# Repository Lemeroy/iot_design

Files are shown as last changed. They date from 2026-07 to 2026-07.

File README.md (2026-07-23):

# 卒中卫士 · StrokeGuard

基于 ESP32-S3 多模态感知的脑卒中风险提示智能健康镜。

> 当前权威架构：ESP32-S3 独立完成感知、融合、告警和云端通信；PC 仅作同局域网监控与标定工具。详细设计见 [独立镜端架构规格](docs/superpowers/specs/2026-07-11-standalone-edge-mirror-design.md)。

## 架构

```text
GC2145 + INMP441 + Wi-Fi CSI
              │
              v
┌────────────────────────────────────┐
│ ESP32-S3-WROOM-1 N16R8 独立镜端    │
│ F/S/T/E/B 边缘评分 · 确定性融合     │
│ TFT/语音/LED/蜂鸣器 · 离线告警      │
└──────────────┬─────────────────────┘
               │ MQTT：仅数值评分/建议文本
               v
┌────────────────────────────────────┐
│ EMQX · InfluxDB · FastAPI · 豆包   │
└────────────────────────────────────┘

可选 PC ──同局域网 HTTP──> 状态监控、受限档案配置
```

- 三类物理感知来源：摄像头、麦克风、Wi-Fi CSI。
- 五个评分模态：面部 F、言语 S、舌偏辅助 T、眼动 E、稳定性 B。
- 原始音视频只在镜端处理，绝不上云。局域网原始校准流默认关闭，必须经认证、物理按键授权、可见提示并自动超时。
- 云端大模型只生成建议文本，不能修改或取消镜端确定性告警。
- 产品用于风险提示和就医提醒，不是医疗诊断设备。
- Arm 因镜子视野限制不单独测量；如需补全，应另配可穿戴或外部设备。

## 目录

```text
strokeguard/
├── firmware_esp32/  # ESP-IDF 5.5.3 固件；当前含 CSI、USB、融合和外设脚手架
├── host_pc/         # PyQt5 管理端及 PC 算法对照原型，不是运行依赖
├── cloud/           # EMQX、InfluxDB、FastAPI、大模型和微信小程序
├── docs/            # 架构规格、接线和实施计划
└── scripts/         # 本地与云端部署/联调脚本
```

## 核心契约

### S3 到云端

```text
Topic: strokeguard/<device_id>/uplink
```

```json
{
  "schema_version": 1,
  "seq": 0,
  "scores": {"face": 0, "speech": 0, "tongue": 0, "eye": 0, "csi": 0, "final": 0},
  "level": "normal|warning|danger|insufficient",
  "profile": {"age": 0, "conditions": []},
  "reasons": [],
  "veto_by": [],
  "device_id": "sg-0001",
  "ts": 0
}
```

禁止字段：原始 JPEG、音频、MFCC、关键点和其他可还原生物特征的数据。

### 云端到 S3

```text
Topic: strokeguard/<device_id>/downlink
```

```json
{"schema_version":1,"level":"warning","advice_text":"给本人或家属的安全建议文本","ts":0,"source":"doubao"}
```

### PC 监控

```text
GET  /api/v1/config
PUT  /api/v1/config
```

当前接口只允许读取完整配置和更新 `profile`，采用 Bearer Token、固定请求上限和 revision 乐观锁。Token 存在镜端 NVS 与 PC 系统凭据库，不进入 YAML。设备 ID、网络、MQTT、融合权重、危险阈值和否决规则均不可通过该接口修改。详见 [PC 配置手册](docs/pc-yaml-config.md)。

校准、模型更新和 OTA 仍是规划项；后续实现必须经过认证、镜端物理确认、签名校验和失败回滚。USB-CDC 只用于烧录、恢复和调试遥测，不承担正常运行时的评分输入。

## 融合规则

```text
final = 0.35 * F + 0.25 * S + 0.20 * T + 0.12 * E + 0.08 * B
```

- `face <= 30` 或口角偏移绝对值 `>= 20°`：`danger`。
- `speech <= 35` 且 `p_clear < 0.4`：`danger`。
- 无否决时：`final >= 70` 为 `normal`，`40 <= final < 70` 为 `warning`，`final < 40` 为 `danger`。
- T 只作辅助，不设置单项否决。可用权重不足时返回 `insufficient`，不得把缺失数据当正常。

阈值是项目实现基线，尚不是经临床验证的诊断阈值；精度、时延和 CSI 标定结果均待真机与合规数据实测。

## 当前状态

| 能力 | 状态 |
| --- | --- |
| CSI 端侧评分、USB 帧协议、S3 融合 C 实现 | 已有原型 |
| PC 五模态算法原型与 PyQt5 UI | 已有；当前作为可选监控与 YAML 管理工具 |
| EMQX、InfluxDB、FastAPI、豆包建议链路 | 已部署并完成链路验证 |
| S3 直连 MQTT 与独立离线闭环 | E1 固件已上板；离线融合、CSI、数值上行、InfluxDB 落库及大模型建议下行已完成真机验证 |
| GC2145/INMP441 边缘模型及训练权重 | 未完成；外设和数据到位后实测 |
| 局域网档案管理 API | GET/PUT、鉴权、revision 冲突与 PC Keyring 已完成 |
| 校准、签名更新与 OTA | 未完成；E5/E6 交付 |

## 开发入口

固件环境：ESP32-S3-WROOM-1 N16R8、ESP-IDF v5.5.3、当前串口 `COM3`。
         ESP32-S3-Camera、ESP-IDF v5.5.3、当前串口 `COM4`
```powershell
cd firmware_esp32
idf.py set-target esp32s3
idf.py menuconfig
idf.py build
idf.py -p COM3 flash monitor
```

### 给另一块 ESP32-S3 烧录固件

以下流程只适用于与当前开发板一致的 **ESP32-S3-WROOM-1 N16R8（16 MB Flash、8 MB OPI PSRAM）**。其他 S3 模组的 Flash/PSRAM 配置可能不同，不要直接照搬镜像。

1. 打开 `C:\Users\Administrator\Desktop\IDF_v5.5.3_Powershell.lnk`，进入固件目录并确认新板串口：

   ```powershell
   cd F:\iot_design\firmware_esp32
   Get-CimInstance Win32_SerialPort | Select-Object DeviceID,Name
   idf.py --version
   ```

2. 为新设备配置独立参数：

   ```powershell
   idf.py set-target esp32s3
   idf.py menuconfig
   ```

   在 `StrokeGuard M1a/M1b Config` 中设置 2.4 GHz Wi-Fi、MQTT 地址/账号及唯一 `Device ID`（例如 `sg-0002`）。多块镜子不能共用同一个 `Device ID`，否则网页监控和 MQTT 主题会互相覆盖。不要把生成的 `sdkconfig` 或任何密码提交到 Git。

3. 将下面的 `COM5` 替换为新板实际串口，清除旧 NVS 后构建、烧录并观察启动日志：

   ```powershell
   idf.py -p COM5 erase-flash
   idf.py build
   idf.py -p COM5 flash monitor
   ```

   `erase-flash` 会清除该板原有固件和 NVS，仅对确认可覆盖的目标板执行。退出串口监视按 `Ctrl+]`。

4. 验收：日志应出现 Wi-Fi `GOT_IP`、CSI 启动和 MQTT 连接/上行；随后通过外网演示页连接该板的 `Device ID`，确认 CSI、最终状态和大模型建议能够同步。

若多块板使用**完全相同**的配置，可先执行一次 `idf.py build`，之后逐块更换串口并运行 `idf.py -p COMx flash`，无需重复编译。但正式多设备部署仍应逐块设置唯一 `Device ID` 后重新构建、烧录。详细故障处理见 [固件 README](firmware_esp32/README.md)。

PC 测试：

```powershell
cd host_pc
.venv\Scripts\python.exe -m pytest -q
```

外设引脚尚未由实物接线确认，固件 Kconfig 默认使用 `-1` 表示未分配；不要按猜测启用驱动。接线状态见 [wiring.md](docs/wiring.md)。

## 初赛桌面演示程序

`dist/StrokeGuard-Demo.exe` 默认连接 VPS 上的真实设备 `sg-0001`，只显示实时 F/S/T/E/CSI、镜端融合状态和最新豆包建议。它不提供模拟数据；云端不可达、登录失效、设备离线和模态未接入会分别显示。数据不足时融合评分显示“未形成”，不会把无效的 `0` 误显示为危险评分。

“设备维护”页提供：

- 部署 YAML 编辑与严格校验；
- `device_id`、2.4 GHz Wi-Fi、MQTT 和管理 Token 的运行时输入；
- GC2145 与 NMO432 配置校验，未填写完整 GPIO 时禁止启用；
- COM 口扫描、ESP-IDF v5.5.3 编译、确认后擦除、烧录和串口日志；
- 敏感字段日志脱敏。

启动 EXE 后输入 VPS 演示账号和密码，程序自动连接 `sg-0001`。账号和密码只保留在当前进程会话中。设备部署密钥应通过界面运行时输入或本机环境变量提供，不得写入 Git。

## Preliminary External Monitor

### Camera score link

The camera board and N16R8 use independent USB power and share GND. Connect
camera `GPIO47/SDA` to N16R8 `GPIO8/SDA` and camera `GPIO48/SCL` to N16R8
`GPIO9/SCL`. The camera is the I2C target at address `0x52`; only numeric
F/E/T/stage values cross this link. Raw images remain local.

The authenticated preliminary monitor connects by device ID only after a valid
MQTT uplink in the last 30 seconds. It synchronizes numeric scores, screening
stage, status, and latest LLM advice. Its only device command is bounded
`start`/`cancel` for a guided F/E/T session; it cannot change Wi-Fi, MQTT,
fusion weights, thresholds, veto rules, firmware, or profile. State uses
WebSocket updates with automatic five-second polling fallback.

Invalid image regions remain unavailable. E is an ocular-movement risk prompt
and does not test visual fields; T is auxiliary and never a single-item veto.

HTTPS is the normal mode. Plain HTTP is allowed only for the preliminary demo with `SG_ALLOW_INSECURE_HTTP=1`. Raw audio, raw video, MFCC, landmarks, and ROI remain local and do not appear in demo API or deployment examples.

## Local Camera USB Preview

For GC2145 bring-up only, close other COM4 monitors and run:

```powershell
host_pc\.venv\Scripts\python.exe host_pc\tools\camera_usb_preview.py --port COM4
```

The link uses `921600 8N1`. Frames are requested one at a time, displayed only
in memory, and are not saved or uploaded. The VPS and large-model service never
receive preview images. N16R8 I2C polling remains active during preview.

## 桌面演示机 3D 模型

可打印 OpenSCAD/STL、装配图、爆炸图与打印验收说明位于
[`mechanical/desktop_enclosure`](mechanical/desktop_enclosure/README.md)。紧凑镜身为
`110 x 165 x 40 mm`，使用单件 `front_panel.stl` 和 `12 mm` 圆形摄像头孔；生产目录
仅保留五个当前打印件：壳体、前面板、一体式可拆电子托盘、后盖和桌面底座。摄像头、
N16R8 与 NMO432 先用扎带安装到托盘，再从壳体后方整体插入；开发板孔距和装配间隙
保持参数化，不使用猜测尺寸。

## 医学免责声明

本设备是家庭健康风险提示工具，不是医疗诊断设备，不能替代医生的临床评估与治疗建议。若出现突发面部歪斜、言语不清、单侧肢体无力、视物异常、平衡障碍或意识改变等症状，无论设备结果如何，都应立即拨打 120，不等待复测或云端建议。

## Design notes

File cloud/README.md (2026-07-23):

# 卒中卫士 · 云端 (M5)

优云 VPS 自建 EMQX + InfluxDB + FastAPI + 火山豆包 doubao-1.5-lite。

## 目录

```
cloud/
├── docker-compose.yml
├── .env.example              # 复制为 .env 并填写
├── native/                   # 无 Docker/systemd 的原生部署
│   ├── install.sh            # 下载并校验固定版本运行时
│   ├── start.sh / stop.sh    # 服务生命周期
│   ├── status.sh             # 进程与端口状态
│   └── healthcheck.sh        # 自动化健康检查
├── scripts/
│   ├── gen_certs.sh          # 生成 EMQX 自签 TLS (无域名场景)
│   └── init_mqtt_users.sh    # 创建 MQTT 业务账号
├── emqx/
│   └── certs/                # 证书目录 (脚本填充)
├── backend/
│   ├── Dockerfile
│   ├── requirements.txt
│   └── app/
│       ├── main.py           # FastAPI 入口
│       ├── mqtt_bridge.py    # 订阅 uplink -> Influx + LLM -> 发布 downlink
│       ├── llm_advice.py     # 豆包 doubao-1.5-lite (Volcengine Ark OpenAI 兼容)
│       ├── db_influx.py      # InfluxDB 2.7 writer
│       └── schemas.py        # pydantic 契约
└── miniapp/                  # 微信小程序 (本地预览)
    ├── app.json / app.js / app.wxss
    └── pages/index/
```

## 当前云容器：原生部署（推荐）

当前实例的 PID 1 是 `tini`，并缺少 Docker-in-Docker 所需的
`CAP_SYS_ADMIN`/`CAP_NET_ADMIN`。请使用项目内原生运行时：

```bash
cd /opt/strokeguard/cloud
bash native/install.sh
bash native/start.sh
bash native/status.sh
bash native/healthcheck.sh
```

运行内容全部位于 `cloud/native/`：

- `runtime/`：EMQX 5.7.2、InfluxDB 2.7.11、Python venv
- `state/`：数据库和 EMQX 持久数据
- `logs/`：服务日志
- `run/`：PID 文件
- `downloads/`：经过 SHA256 校验的官方安装包

停止与重启：

```bash
bash native/stop.sh
bash native/start.sh
```

云容器整体重启后需要再次运行 `bash /opt/strokeguard/cloud/native/start.sh`。
若控制台支持“启动命令”，可直接填写该命令。脚本不会修改平台挂载的
`/entrypoint.sh`。

本地 Windows 一键上传并部署：

```powershell
powershell -ExecutionPolicy Bypass -File F:\iot_design\scripts\deploy_cloud_native_interactive.ps1
```

该窗口会分别在上传和远端部署时请求一次 SSH 密码，密码不会写入文件。

若云平台尚未开放公网业务端口，可先在本机建立 SSH 隧道：

```powershell
powershell -ExecutionPolicy Bypass -File F:\iot_design\scripts\open_cloud_tunnel.ps1
```

保持隧道窗口开启，并让上位机使用：

```powershell
$env:SG_MQTT_HOST="127.0.0.1"
$env:SG_MQTT_PORT="11883"
```

本机 FastAPI 为 `http://127.0.0.1:18000`，EMQX Dashboard 为
`http://127.0.0.1:18084`。这些端口只绑定本机回环地址。

## 标准 VPS：Docker Compose 部署

## 部署到 VPS (Ubuntu 22.04, Docker 已装)

### 1. 上传 cloud/ 到服务器

在**本地** PowerShell:

```powershell
# 用 scp 上传 (端口 22)
scp -P 22 -r F:\iot_design\cloud ubuntu@<VPS_HOST>:/tmp/strokeguard-cloud
ssh ubuntu@<VPS_HOST>
sudo mkdir -p /opt/strokeguard
sudo mv /tmp/strokeguard-cloud /opt/strokeguard/cloud
sudo chown -R ubuntu:ubuntu /opt/strokeguard/cloud
```

### 2. 配置 .env

在**服务器**上:

```bash
cd /opt/strokeguard/cloud
cp .env.example .env
vim .env    # 填写下列 5 项:
```

必填:
- `EMQX_DASHBOARD_PASS` — EMQX 18083 管理面板密码
- `MQTT_APP_PASS` — backend 用的 MQTT 密码 (随机字符串)
- `MQTT_HOST_PASS` — host_pc 上位机用的 MQTT 密码 (随机)
- `INFLUX_TOKEN` — 长随机串, 用 `openssl rand -hex 32` 生成
- `VOLC_ARK_API_KEY` — 火山方舟 API Key

### 3. 生成 TLS 证书 (无域名, 用 IP)

```bash
cd /opt/strokeguard/cloud
bash scripts/gen_certs.sh <VPS_HOST>
```

生成 `emqx/certs/ca.crt server.crt server.key`. 客户端将来需要 `ca.crt`.

### 4. 启动

```bash
docker compose up -d
docker compose ps           # 三个容器都是 running
docker compose logs -f backend
```

### 5. 创建 MQTT 账号

```bash
bash scripts/init_mqtt_users.sh
```

### 6. 联调验证

```bash
# 后端健康
curl http://127.0.0.1:8000/health
# {"status":"ok","mqtt":true,"influx":true,"llm":true}

# 手动触发一次 LLM 建议 (不经过 MQTT)
curl -X POST http://127.0.0.1:8000/advice \
  -H "Content-Type: application/json" \
  -d '{
    "scores": {"face":25,"speech":40,"tongue":100,"eye":90,"csi":80,"final":45},
    "level": "danger",
    "profile": {"age":68,"gender":"M","conditions":["hypertension"],"meds":["aspirin"],"stroke_history":false},
    "reasons": ["mouth_angle 22.5deg"]
  }'
```

## host_pc 上位机连云

设置环境变量后启动主界面:

```powershell
$env:SG_MQTT_HOST="<VPS_HOST>"
$env:SG_MQTT_PORT="1883"          # 联调期先用明文; 生产改 8883 + SG_MQTT_TLS=1
$env:SG_MQTT_USER="<MQTT_DEVICE_USER>"
$env:SG_MQTT_PASS="<你在 .env 里填的 MQTT_HOST_PASS>"
$env:SG_DEVICE_ID="sg-0001"

python -m stroke_host.ui.main_window --source real --perception
# 勾选 UI 顶部 Cloud 复选框, 然后 Start
```

启动后:
- host_pc 每 10s (或 level 变化时) uplink 数值评分
- 后端订阅 uplink -> 写 Influx -> 调豆包 -> 发布 downlink
- host_pc 收到 downlink -> UI 建议卡片显示

## 数据契约

见 `backend/app/schemas.py`. 三条主管线:

| 方向 | Topic | 载荷 |
|---|---|---|
| host->cloud | `strokeguard/<dev>/uplink` | `UplinkPayload` |
| cloud->device | `strokeguard/<dev>/downlink` | `DownlinkPayload` |
| miniapp<-cloud | HTTP `/devices/<dev>/latest` | `LatestResp` |

**隐私铁律**: 云端接收的载荷**只有数值分与 profile**, 不含 jpeg/mfcc/坐标. `mqtt_pub.py` 已做严格过滤.

## Preliminary External Monitor

The preliminary external page is a read-only monitor. After login, it connects by device ID only when that device has produced a valid MQTT uplink in the last 30 seconds. It synchronizes only monitoring scores/status and the latest LLM advice.

The score panel is session-based: starting a screening clears the displayed
scores to pending, stages 1-4 collect values without repainting the panel,
stage 5 shows the highest observed F/E values from those preceding stages, and
the completed panel is held for 30 seconds. This is display stabilization only;
device-side fusion, vetoes, alerts, and uploaded numeric scores are unchanged.

It does not synchronize profile, Wi-Fi, MQTT settings, fusion settings, thresholds, veto rules, or remote commands. Raw audio, raw video, MFCC, landmarks, and ROI stay local and are excluded from demo API and deployment examples.

HTTPS is the normal mode. Plain HTTP is allowed only for the preliminary demo when `SG_ALLOW_INSECURE_HTTP=1`; otherwise session cookies remain secure. Set `SG_DEMO_USER`, `SG_DEMO_PASSWORD`, and `SG_DEMO_SESSION_SECRET` together to enable demo login. Leaving any of them incomplete keeps authentication disabled so the normal cloud chain still starts.

## 微信小程序本地预览

无 AppID (touristappid) 只能在**微信开发者工具**里预览:

1. 装 [微信开发者工具](https://developers.weixin.qq.com/miniprogram/dev/devtools/download.html)
2. 打开 `cloud/miniapp/` 目录, 选 "无 AppID 测试"
3. `app.js` 里的 `apiBase` 改成你的 VPS IP
4. 顶部工具 -> 详情 -> 本地设置 -> 勾选 "不校验合法域名..."
5. 编译预览

真机预览需要注册 AppID + HTTPS + 域名 ICP 备案, 属于毕设外围, M5 不做.

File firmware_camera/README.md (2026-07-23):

# StrokeGuard Camera Coprocessor

This ESP-IDF v5.5.3 project targets the Hiwonder ESP32-S3-Cam board
(`ESP32-S3-WROOM-1U-N8R8`) with the onboard GC2145 camera. It runs local
`esp32-camera` YUV422 capture, local PSRAM RGB888 conversion, and ESP-WHO
`human_face_detect`. It computes a quality-gated FAST Face (F) engineering
score from ESP-WHO's five landmarks and a volatile personal neutral baseline.
During an explicitly started guided session it also computes local pupil-motion
E and auxiliary tongue-deviation T scores, then exposes only numeric results to
the N16R8 main controller over I2C.

Raw images are not uploaded. The normal device output is face presence and
normalized geometry only. An explicit USB debug session may send requested
JPEG frames directly to the attached PC; frames are not saved or uploaded.
The USB face box remains a detection diagnostic. The five-point F score is a
risk feature, not a diagnosis, and is not equivalent to evaluated 68-point
facial analysis.

## Wiring

Both boards are powered by their own USB cables. Keep the 5 V jumper between
boards disconnected. Share ground.

| Camera board signal | Camera GPIO | N16R8 GPIO |
| --- | ---: | ---: |
| SDA | 47 | 8 |
| SCL | 48 | 9 |
| GND | GND | GND |

The camera's internal GC2145 DVP/SCCB pins are configured in
`main/camera_capture_adapter.cpp` from the vendor example:

```text
XCLK=15, SCCB_SDA=4, SCCB_SCL=5
D0..D7 = 11,9,8,10,12,18,17,16
VSYNC=6, HREF=7, PCLK=13
```

GC2145 does not provide native JPEG output through `esp32-camera`. The
firmware captures QVGA YUV422 and converts it locally to a reusable RGB888
PSRAM buffer for ESP-WHO. An explicit USB preview request encodes the original
YUV422 frame to JPEG locally; it does not change the normal I2C-only output.
The `esp32-camera` converter emits BGR byte order for YUV422 input, so the
adapter swaps the red and blue channels before ESP-WHO preprocessing. Removing
that normalization prevents reliable face detection on the real board.
The camera uses one frame buffer with `CAMERA_GRAB_WHEN_EMPTY`; real-board
testing showed that the two-buffer latest-frame mode spliced DMA regions from
different frames. The resulting frame rate and inference latency are pending
final measurement.

## I2C Protocol

The camera board is the I2C target on GPIO47/GPIO48:

```text
address:  0x52
register 0x01: 4 bytes: center_x, center_y, width, height
register 0x02: 4 bytes: status, F_score, signed_mouth_angle, quality
register 0x03: 4 bytes: status, E_score, binocular_difference, quality
register 0x04: 4 bytes: status, T_score, signed_offset_percent, quality
register 0x10: write 2 bytes: register, start(1)/cancel(0)
register 0x11: 4 bytes: stage, progress, 0, 0
```

Register `0x01` values are normalized to `0..255`; all zeros mean no face.
For register `0x02`, status `1` means the remaining values are valid and
status `0` means F is unavailable. Score and quality are `0..100`; angle is a
signed degree value in `-90..90`. N16R8 uses register `0x02` for fusion.

Stages are `idle`, `face`, `eye-center`, `eye-left`, `eye-right`, `tongue`,
`done`, and `error`. E and T remain unavailable outside a guided session or
when image quality gates fail. E does not claim visual-field testing. T is an
auxiliary observation only and never acts as a single-item danger veto.
If the tongue stage times out without three valid samples, the session enters
`error` and T remains unavailable; no zero or synthetic tongue score is sent
to fusion.
The tongue color candidate must also extend below the detected mouth line;
lip-colored regions without protrusion remain unavailable.
During a new guided run, the previous valid E/T values remain visible until
replacement results are ready. A tongue-stage failure clears T immediately.
Guided eye steps that do not move in opposite directions are treated as an
unavailable acquisition, not E=0; continuous eye monitoring remains available.

The F feature requires a face at least 64 pixels wide, sufficient eye spacing,
a near-frontal nose position, and eye-line roll within 25 degrees. It removes
eye-line roll from the mouth angle, combines mouth angle with nose-to-mouth
distance asymmetry, and publishes a three-frame median relative to a five-sample
neutral baseline. These are
initial engineering thresholds pending measured sensitivity, specificity,
and K-fold evaluation.

## Build And Flash

Open `C:\Users\Administrator\Desktop\IDF_v5.5.3_Powershell.lnk`:

```powershell
cd F:\iot_design\firmware_camera
idf.py set-target esp32s3
idf.py build
idf.py -p COM4 flash monitor
```

The app uses a custom `3 MB` factory partition and `8 MB` flash because the
embedded ESP-WHO model is larger than the default 1 MB app partition.

## Local USB Preview

Close every COM4 serial monitor before opening the preview; COM4 must be closed
by other programs because one process owns the port. From the repository root:

```powershell
host_pc\.venv\Scripts\python.exe host_pc\tools\camera_usb_preview.py --port COM4
```

The debug protocol uses `921600 8N1`. The PC requests one JPEG at a time, so
preview work stops when the window disconnects. Images remain on the directly
connected PC, are not saved, and are not uploaded to MQTT, VPS, or the large
model. I2C numeric F polling at `0x52`/`0x02` continues during preview.

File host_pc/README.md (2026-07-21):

# StrokeGuard PC 端 M1a

## 初赛演示入口（推荐）

```powershell
cd F:\iot_design\host_pc
.venv\Scripts\python.exe -m stroke_host.demo.window
```

该入口是 `StrokeGuard-Demo.exe` 的源码运行方式：默认登录 VPS 并连接真实设备 `sg-0001`，不读取模拟源、不运行 PC 感知管线，也不生成替代评分。设备维护页可编辑 `config/device-deployment.example.yaml`，填写本次运行使用的 Wi-Fi/MQTT/管理凭据，调用本机 ESP-IDF v5.5.3 完成编译、确认擦除、烧录和串口监视。

麦克风型号为 **NMO432**：3.3V 供电，I2S 引脚为 `SCK/BCLK`、`WS/LRCLK`、`SD/DIN`，并通过 `L/R` 选择声道。GC2145 与 NMO432 的 GPIO 未完整确认时保持 `enabled: false`，程序不会猜测引脚。

下文的模拟源、PC 感知和旧观察窗口仅供研发测试，不属于初赛 EXE 的演示入口。

上位机数据管线：ESP32 帧接入 + AES-GCM 加密落盘 + 24h 自动清理 + 用户档案。

## 目录

```
host_pc/
├── pyproject.toml
├── requirements.txt
├── config/
│   └── profile.yaml            # 用户档案 (age/conditions/meds/...)
├── stroke_host/
│   ├── main.py                 # 入口 CLI
│   ├── io/
│   │   ├── cdc_reader.py       # ESP32 USB-CDC 帧解析
│   │   ├── sim_source.py       # 无硬件桩 (M1a 默认)
│   │   ├── frame_recorder.py   # AES-GCM 落盘 + 定时清理
│   │   └── crc16.py            # 与固件对齐
│   ├── config/profile_loader.py
│   └── utils/crypto.py         # keyring master key + AESGCM
└── tests/                      # pytest (含 CRC 对拍 / 帧解析 / 加密 / 24h 清理)
```

## 安装 (Windows PowerShell)

```powershell
cd F:\物联网设计\host_pc
python -m venv .venv
.\.venv\Scripts\Activate.ps1
python -m pip install -U pip
pip install -e ".[dev]"
```

## 跑桩数据源 (无 ESP32, M1a 默认)

```powershell
python -m stroke_host.main --source sim
# 每秒一帧 heartbeat, csi_score 60~95 随机游走
# Ctrl+C 停止, 落盘至 data\session_<时间>\frames.jsonl.enc
```

## 跑真机 (烧录线到手后)

```powershell
# 先确认哪个 COM 是数据口 (CDC0, Interface 0)
Get-CimInstance Win32_SerialPort | Select-Object Name,DeviceID,Description

python -m stroke_host.main --source cdc --port COM3
```

统计输出示例：

```
cdc stats: ok=612 crc_err=0 resync=1
```

## 实时观察窗口 (M1a Observer, tkinter)

零新增依赖，用于目视监控 csi_score 趋势。

```powershell
python -m stroke_host.gui.observer --source sim
# 或真机
python -m stroke_host.gui.observer --source cdc --port COM3
```

窗口包含：
- 交通灯：red (<30) / yellow (<60) / green (>=60)
- 大号 csi 数字 + 最近 60 帧 sparkline
- 统计：frames / fps / cdc ok/crc_err/resync / 当前 session 目录名
- 日志尾 30 行
- 顶部工具条：切 sim/cdc、改 port、勾选 Record、Start/Stop

## M2 感知算法 (F 面部对称 + S 语音清晰度)

新增依赖：`mediapipe` (可选，未装则 F 分不可用)

```powershell
pip install mediapipe
```

真源模式跑 PC 摄像头+麦克风，同时出 F/S 分：

```powershell
python -m stroke_host.main --source real --perception --no-record
```

输出示例：

```
[#12] data csi=None ts=2  F=94 (mouth_angle 1.7deg)  S=63
[#13] data csi=None ts=2  F=97
```

模块概览：

| 模块 | 功能 | 备注 |
|---|---|---|
| `perception/face_detect.py` | mediapipe FaceMesh 468/478 点封装 (refine_landmarks=True 含虹膜) | 单人 |
| `perception/face_symmetry.py` | 口角连线 θ → F 分 (0-100) | 用双眼外眦补偿头部面内旋转 |
| `perception/landmark68.py` | 468 → iBUG 68 点索引映射 | 供 dlib 兼容脚本复用 |
| `perception/mfcc.py` | 纯 numpy MFCC | 与嵌入式 C 版可 bitmatch |
| `perception/mic_source.py` | sounddevice 系统默认输入 | 16 kHz mono |
| `perception/speech_cnn.py` | S 分, CNN 未训 → 启发式 fallback | `p_clear` 综合 voiced_ratio/HNR/MFCC 稳态 |
| **`perception/tongue_deviation.py`** | Tongue 分 (辅助, 权重 0.08) | 下唇内侧近似, **低置信度不否决** |
| **`perception/eye_gaze.py`** | E 分 (权重 0.12) | mediapipe 虹膜, gaze 共轭比 + 眼裂对称性 |
| **`perception/csi_score.py`** | B 分 (权重 0.08) | 端侧已算, PC 侧透传 |

### Dr.Chen 阈值 (v0, 待临床验证)

| 模态 | 计算 | Danger 线 | Warning 线 |
|---|---|---|---|
| F 面部 | `100 - 4·θ` | θ ≥ 20° | θ > 10° |
| S 言语 | `100·p_clear` | score<35 且 p<0.4 | score<55 |
| T 舌偏 | 分段 (辅助) | r≥0.15 → 30 | r≥0.10 → 50-70 |
| E 眼动 | `100 - 200·|Δgaze|` | dg≥0.30 或 lid_asym | dg≥0.15 |
| B 平衡 (CSI) | 端侧直接输出 | <30 | <60 |

**局限（明示）**：
- F: mediapipe 二维投影对大侧脸敏感
- S: 无临床构音数据集，走启发式，需 SNR>15dB
- T: 无舌头分割模型，本版为下唇偏移近似，**灵敏度低，仅参考**
- E: 需正视镜头 ±20°；戴墨镜/极暗光 iris 失败 → unavailable
- B: 无外发射器，反映"存在感/剧烈动作"而非精确平衡

## 观察窗口升级 (M2+M3, 5 模态卡片)

```powershell
python -m stroke_host.gui.observer --source real --perception
```

窗口现包含：
- 总指示交通灯 + 大号"最低模态分"数字（宁误报保守策略）
- **5 张模态卡片**：F / S / T / E / B，各自变色 + 数字
- 60 帧 sparkline
- Perception 复选框（勾选后 data 帧走完整感知流水线）

## M4 主界面 (PyQt5 · 正式版)

新增依赖：

```powershell
pip install -e ".[ui]"     # 安装 PyQt5 + pyttsx3
```

启动：

```powershell
python -m stroke_host.ui.main_window --source real --perception
```

功能：

- **五模态融合**：`final = 0.35·F + 0.35·S + 0.08·T + 0.14·E + 0.08·B`
- **单项否决**（Ark + Dr.Chen 会签，宁误报）：
  - F ≤ 30 或 mouth_angle ≥ 20° → **danger**（红灯闪烁 + 语音"检测到面部不对称,请立即就医并拨打 120"）
  - S ≤ 35 且 p_clear < 0.4 → **danger**（"检测到言语不清..."）
  - E < 30 或 B < 30 → 从 normal 提升为 **warning**
- **不可用模态自适应**：某模态 score=-1 时权重按比例重分；可用总权重 <0.5 → level="insufficient"
- **UI 组成**：
  - 左：180×180 交通灯（danger 时 400ms 闪烁）+ 大号 final + 中文 level 文本 + reasons 面板
  - 右：5 张模态卡片（边框跟随各自阈值变色）
  - 语音引导按钮：**请微笑** / **请说"你好中国"** / **请正视镜头**
  - 顶部工具条：source / port / Record / Perception / Voice alerts
  - 底部：帧率统计 + 完整免责声明
- **TTS**：`pyttsx3` (SAPI5，Windows 自带)，异步线程 + 3s 冷却期防轰炸，未装或初始化失败自动降级为静默
- **加密录制**：Record 勾选时启用 AES-GCM + 24h 清理 (M1a 一致)

## 完整模块清单

```
host_pc/stroke_host/
├── io/                  # M1a: CDC 帧解析 / sim / real / 加密落盘
├── perception/          # M2+M3: F / S / T / E / B
├── fusion/              # M4: 加权 + 单项否决 + 分级
├── ui/                  # M4: PyQt5 主界面 + pyttsx3 TTS
├── gui/                 # M1a Observer (tk, 调试用)
├── config/              # profile.yaml 加载
├── utils/               # AES-GCM + keyring
└── main.py              # CLI 入口
```

## 测试

```powershell
pytest -q
```

覆盖：
- CRC16 与固件对拍向量 (`test_crc16.py`)
- 帧同步 / CRC 错帧丢弃 / 头前垃圾自动重同步 (`test_cdc_parser.py`)
- AES-GCM 往返 + 25h 前旧 session 被清理 + 当前 session 不被误删 (`test_frame_recorder.py`)
- `profile.yaml` 校验 (`test_profile.py`)
- Sim 源端到端跑通 (`test_integration_sim.py`)

## 隐私 & 安全

| 项 | 实现 |
|----|---|
| Master key | Windows 凭据管理器 (keyring)，`Service=StrokeGuard, Account=master-key` |
| 加密 | AES-256-GCM，每帧独立 12B nonce，AAD=device_id |
| 保留期 | 24 小时；后台线程每 30 分钟扫描一次 |
| 上云 | M1a **不上云**；M5 起只传数值评分 + profile |

## Quinn 验收 (M1a PC 端)

| # | 步骤 | 通过标准 |
|---|---|---|
| P1 | `pip install -e ".[dev]"` | 无 error |
| P2 | `pytest -q` | 全绿 |
| P3 | `python -m stroke_host.main --source sim --max-frames 10` | 打印 10 条 heartbeat 后退出 |
| P4 | 查看 `data\session_*\frames.jsonl.enc` | 存在且非空 |

真机联调 (Q4-Q6) 待烧录线到手后一起跑。

## 已知局限

- SimSource 只产 heartbeat，不产图像/音频；M2 开始加 PC 摄像头/麦克风真源
- 时间戳来自 `time.time()`，未做 ESP32 端时间同步（M5 SNTP 处理）
- 无 SNTP 时 ESP32 `ts` 是启动后秒数，PC 侧只信 `ts_recv`

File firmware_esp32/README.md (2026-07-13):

# StrokeGuard 固件 E1 (v0.5)

ESP32-S3-WROOM-1 (N16R8) · IDF v5.5.3 · **独立本地融合/告警** + Wi-Fi CSI + MQTT 数值上报 + USB-Serial-JTAG 调试遥测。

> v0.3 变更 (2026-07-10):
> - **CSI 算法升级为三特征融合** (借鉴 [RuView, MIT](https://github.com/ruvnet/RuView) 信号处理章节):
>   幅度 CV (0.40) + 相位方差 (0.40) + 运动带能量 (0.20)
> - 相位方差不受 AGC 影响, 静止/动作区分度更好
> - **新增 1 Hz ICMP ping 网关**保证 CSI 包流量 (STA 空闲时 CSI 极稀疏)
> - `task_csi` 加 5s **静默诊断日志**: 让 "回调未触发" 与 "样本不足" 两种情况可肉眼区分
>
> v0.2: 放弃 TinyUSB 双 CDC, 改用 IDF 内置 `usb_serial_jtag` 单口。

## 目录

```
firmware_esp32/
├── CMakeLists.txt
├── sdkconfig.defaults      # PSRAM OPI / usb_serial_jtag / CSI 使能
├── partitions.csv          # OTA 预留
└── main/
    ├── app_main.c          # 启动 & 心跳任务
    ├── app_config.h        # 全局宏 (含三特征权重)
    ├── usb_cdc_proto.*     # usb_serial_jtag + 帧封装
    ├── crc16.*             # CRC16-CCITT
    ├── csi_monitor.*       # CSI 采集 + 三特征打分 (RuView 借鉴)
    ├── csi_ping.c          # 1Hz ICMP keep-alive (RuView 借鉴)
    ├── frame_builder.*     # JSON 组包
    ├── Kconfig.projbuild   # menuconfig 里的 WiFi 配置
    └── log_tag.h
```

## 环境

- ESP-IDF **v5.5.3**，PowerShell (Windows)
- 已 `install.ps1 esp32s3` 并 `. $env:IDF_PATH\export.ps1`

## 配置 WiFi

```powershell
idf.py -p COM3 menuconfig
# -> "StrokeGuard M1a Config" -> 修改 WiFi SSID/Password -> S 保存 -> Q 退出
```

路由器必须提供 2.4 GHz Wi-Fi；ESP32-S3 不支持 5 GHz。建议锁 2.4 GHz **Ch6, 20MHz**。

## 构建 / 烧录 / 监视

```powershell
idf.py set-target esp32s3
idf.py build
idf.py -p COM3 flash monitor
```

**关键**: v0.2 只有**一个** COM 口, `flash` 和 `monitor` 用同一个 COM3.
`monitor` 里既能看到日志, 也能看到二进制帧(会显示为乱码, 属正常).
USB 帧仅供 PC 端 `stroke_host` 观察和调试；运行时融合、告警和 MQTT 不依赖 PC。

## 烧录到另一块 N16R8

1. 使用 `C:\Users\Administrator\Desktop\IDF_v5.5.3_Powershell.lnk` 打开已加载 ESP-IDF 的 PowerShell。
2. 插入目标板，通过以下命令确认它的新串口，不要默认仍是 `COM3`：

   ```powershell
   Get-CimInstance Win32_SerialPort | Select-Object DeviceID,Name
   cd F:\iot_design\firmware_esp32
   ```

3. 确认目标仍是 ESP32-S3-WROOM-1 **N16R8**，然后运行 `idf.py menuconfig`。在 `StrokeGuard M1a/M1b Config` 中至少检查：

   - `WiFi SSID` / `WiFi Password`：只支持 2.4 GHz Wi-Fi。
   - `Device ID`：每台镜子必须唯一，例如 `sg-0002`、`sg-0003`。
   - `MQTT broker URI` / 用户名 / 密码：与 VPS 的设备接入配置一致。
   - `LAN management token`：按设备单独设置，不能写入 README 或提交 Git。

4. 首次接管一块旧板时，先清除它原有的 NVS，再烧录。将 `COM5` 替换为实际串口：

   ```powershell
   idf.py set-target esp32s3
   idf.py menuconfig
   idf.py -p COM5 erase-flash
   idf.py build
   idf.py -p COM5 flash monitor
   ```

   `erase-flash` 会删除目标板上的全部固件和配置。若确认是空白新板，可直接 `build`、`flash monitor`。按 `Ctrl+]` 退出 monitor。

5. 通过标准：启动日志出现 `GOT_IP`、CSI 启动、MQTT 已连接及周期上行；VPS 外网演示页用对应 `Device ID` 连接后，能看到设备在线、实时 CSI/融合状态与最新大模型建议。当前 F/S/T/E 未接入时显示 `null`/`未接入` 是预期行为。

### 同配置快速复制

同一台电脑上已经成功 `idf.py build` 后，可不重复构建，逐块执行：

```powershell
idf.py -p COM5 flash
idf.py -p COM6 flash
```

这只适合临时复制**完全相同配置**的演示板。由于 `Device ID` 编译在当前配置中，多台正式设备不能直接复制同一构建产物；应修改 `Device ID`、重新 `build` 并逐台烧录。也不要复制整片 Flash/NVS 镜像，因为其中可能包含设备身份和本地凭据。

### 常见问题

- 找不到 `idf.py`：重新从 IDF 5.5.3 快捷方式启动 PowerShell。
- 找不到串口：更换支持数据传输的 USB 线，检查设备管理器，并按住 `BOOT` 后点按 `RESET` 进入下载模式。
- `Failed to connect`：关闭占用该 COM 口的串口监视器/上位机，再进入下载模式重试。
- 烧录后反复复位或 PSRAM 报错：停止使用该镜像，核对目标模组是否确为 N16R8。
- 能连 Wi-Fi 但网页无设备：检查 MQTT 地址和凭据、设备 ID，并确认 VPS 收到最近 30 秒内的上行。

## 局域网档案管理

固件在取得 Wi-Fi 地址且配置了非空管理 Token 后启动 HTTP 服务：

```text
GET /api/v1/config
PUT /api/v1/config
Authorization: Bearer <MANAGEMENT_TOKEN>
```

- Token 仅写入被 Git 忽略的本机 `sdkconfig`，设备首次启动后存入带 CRC 的 NVS v2；不得写入 README、YAML 或日志。
- GET 响应不包含 MQTT 用户名、密码或管理 Token。
- PUT 只接受 `schema_version`、`expected_revision` 和完整 `profile`，拒绝未知字段、网络字段、医学阈值和重复键。
- revision 不匹配返回 `409`；成功持久化后才替换内存快照。
- 请求正文上限 1024 字节，HTTP 任务栈为 12 KB。真机联调证明 6 KB 不足以容纳 PUT 的固定缓冲区与 JSON/NVS 调用栈。
- 当前开发传输是可信局域网内的 HTTP；生产使用必须增加 TLS 或等价的安全隧道。

PC 端配置流程见 [pc-yaml-config.md](../docs/pc-yaml-config.md)。

## 帧协议 v1

```
偏移  长度  字段
0     2B    A5 5A          magic
2     1B    ver = 0x01
3     1B    type           0x01=heartbeat, 0x02=data(M1b), 0xF0=log
4     2B    len (LE)       payload 长度
6     N     payload        UTF-8 JSON
6+N   2B    CRC16-CCITT    覆盖 ver..payload
```

payload 示例:

```json
{"type":"heartbeat","ts":123,"seq":42,"csi_score":87,"fw":"m1a-0.3"}
```

## CSI 三特征融合 (v0.3)

| 特征 | 计算 | 权重 | 含义 |
|---|---|---|---|
| 幅度 CV | `stddev / mean` 全带幅度 | 0.40 | 静止时子载波幅度稳 |
| 相位方差 | unwrap 后 `var(phase)` 参考子载波 | 0.40 | 抗 AGC, 动作敏感 |
| 运动带能量 | 相邻样本 L2 差分归一 | 0.20 | 动作剧烈度 |

分值 `= 100 - k·feature`, 再按权重线性加权。k 值 (`SG_CSI_K_*` 于 `app_config.h`) 需 M6 阶段实测标定。

## Quinn 独立验收 (v0.3)

| # | 步骤 | 通过标准 |
|---|---|---|
| Q1 | `idf.py build` | 无 error |
| Q2 | `flash monitor` | 5s 内 `boot fw=m1a-0.3` |
| Q3 | 15s 内 | `WIFI GOT_IP` 与 `csi started (v0.3 3-feat fusion...)` |
| Q4 | 20s 内 | `ping keep-alive @ gw=xxx.xxx.xxx.xxx` |
| Q5 | 30s 内 | 心跳帧里 `csi_score` 从 `null` 变成 0-100 数字 |
| Q6 | 揉一下头/在镜前挥手 | `csi_score` 明显下跌 (>20 分), 静止后回升 |

## 已知局限

- 打分公式中的 `SG_CSI_K_*` 是经验初值, M6 前需实测标定 (静止/正常动作/剧烈动作三档做校准)
- 无外发射器 → CSI 反映"镜前存在感/剧烈动作", 不是精确平衡评估
- M1a 无外设, heartbeat 帧不含图像/音频, 仅 CSI 分与序号
- 相位 unwrap 只用参考子载波 (n_sub/2), 边缘 SC 抖动更大, 后续可换 SVD 主分量

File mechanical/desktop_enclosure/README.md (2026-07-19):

# StrokeGuard Compact Desktop Enclosure

This package is the manufacturing handoff for the compact StrokeGuard
preliminary-demonstration enclosure. OpenSCAD is the source of truth for fit
and dimensions. The mirror body is limited to `110 x 165 x 40 mm`.

StrokeGuard is a risk-reminder and care-seeking aid, not a diagnostic device.
The enclosure does not establish clinical accuracy, microphone calibration,
thermal certification, ingress protection, or production safety certification.

## Production Files

The `stl/printable/` directory contains exactly five production parts:

- `compact_shell.stl`;
- `front_panel.stl`;
- `electronics_tray.stl`;
- `rear_cover.stl`;
- `desktop_base.stl`.

The one-piece front panel has a centered `12 mm` circular camera aperture. The
removable electronics tray provides a camera cage sized from the supplied
`27 x 42 x 19 mm` module envelope, repeated N16R8 slots, NMO432 slots, and cable
routing. All three modules use cable ties because the supplied drawings do not
give complete mounting-hole coordinates.

The first-print correction uses a `30 mm camera-guide opening`, moves the tray
`2 mm rearward`, and leaves a nominal `0.5 mm assembly gap` between the tray and
rear-cover posts. These are prototype clearances derived from physical fit
feedback, not production tolerances.

Additional delivery files:

- parameters: `scad/parameters.scad`;
- geometry modules: `scad/parts.scad`;
- command-line entry: `scad/strokeguard_enclosure.scad`;
- display STL: `stl/display/strokeguard-display.stl`;
- assembly and exploded renders: `renders/`;
- dimension schedule: `drawings/dimensions.md`.

This revision provides only the integrated electronics tray, rear service
cover, and desktop base needed by the N16R8, camera module, and NMO432. It does
not add ST7789, MAX98357A, RGB LED, buzzer, buttons, or another sensor.

## Tool Setup

Install OpenSCAD on Windows:

```powershell
winget install --id OpenSCAD.OpenSCAD --exact `
  --accept-package-agreements --accept-source-agreements
```

Create the isolated mechanical test environment:

```powershell
cd F:\iot_design
python -m venv mechanical\desktop_enclosure\.venv
mechanical\desktop_enclosure\.venv\Scripts\python.exe -m pip install `
  -r mechanical\desktop_enclosure\requirements-dev.txt
```

Regenerate all committed STL and PNG outputs:

```powershell
powershell -ExecutionPolicy Bypass -File `
  mechanical\desktop_enclosure\scripts\export_models.ps1 -Export -Render
```

Run the geometry and handoff tests:

```powershell
mechanical\desktop_enclosure\.venv\Scripts\python.exe -m pytest `
  mechanical\desktop_enclosure\tests\test_enclosure.py -v
```

## Bambu Studio

Select the built-in Bambu Lab H2S printer profile and the nozzle actually
installed on the printer. Import the five production STL files at `100%`
scale. For a first PLA print with a `0.4 mm` nozzle, use these starting values:

- `0.20 mm` standard layer profile;
- three walls;
- `15-20%` infill;
- support disabled initially, then enabled only where the slicer preview shows
  unsupported geometry.

These are starting settings, not measured guarantees. Use the filament and
build-plate profiles recommended by their manufacturers.

Suggested orientation:

- `front_panel.stl`: smooth visible face on the build plate;
- `compact_shell.stl`: already exported with one broad side wall on the build
  plate; keep the default imported orientation;
- `rear_cover.stl`: largest flat face on the build plate;
- `desktop_base.stl`: bottom face on the build plate;
- `electronics_tray.stl`: broad backplane on the build plate, guides upward.

Inspect the complete slicer preview for closed holes, unsupported rails, thin
walls, and the `12 mm` camera aperture before printing.

## Assembly Order

1. Before installing electronics, test-fit all five printed parts. Slide the
   empty tray in from the rear and confirm that it reaches the shell stop pads
   without binding. Do not force tight rails or fasteners.
2. Deburr the camera aperture, lower acoustic notch, cable exit, and M3 holes.
3. Populate the electronics tray first. Secure the `27 x 42 x 19 mm` camera
   module in the upper cage with cable ties, then align the N16R8 and NMO432 on
   their adjustable slots. Keep the N16R8 antenna area clear of fasteners and
   bundled wiring.
4. Route camera I2C and microphone I2S separately on the tray, add strain
   relief, and leave enough cable for the lower rear exit.
5. Insert the populated tray from the rear until it rests against the shell
   stop pads. Confirm the camera lens is centered in the `12 mm` aperture and
   NMO432 faces the hidden lower acoustic path.
6. Fit the rear cover. Its rear-cover pressure posts retain the tray against the
   shell stops; they are not screw bosses and must not crush a PCB or cable.
7. Install four M3 screws through the rear cover's `3.4 mm` clearance holes into
   the shell's `2.6 mm` printed pilot holes. Attach the body to the base with two
   M3 screws through its `3.4 mm` clearance holes into the reinforced `2.6 mm`
   shell pilots.

When replacing the earlier tight-fitting revision, reprint the shell,
electronics tray, and rear cover. The shell contains the shifted tray stops,
the tray contains the wider camera guides, and the rear cover contains the
shortened posts. The front panel and desktop base do not need reprinting for
this correction unless their physical parts are damaged or out of tolerance.

Select screw lengths only after measuring the printed stack, washers, and any
inserts or nuts. Pilot-hole and screw fit is pending a physical print; drill or
ream cautiously if material shrinkage makes a pilot too tight. Do not force an
overlong screw into a PCB or wire path.

## Physical Acceptance

Repository tests validate digital geometry only. Before presentation:

- verify front-panel and rear-cover fit on the real print;
- verify the camera module clears the rear cover and frames the intended user;
- verify NMO432 response with the enclosure closed;
- verify the base remains stable with final power and debug cables attached;
- verify Wi-Fi operation with the final enclosure and wiring;
- record print time, material use, shrinkage, and surface temperature only as
  measured observations.

Raw audio and video remain local. Mechanical files contain no user profile,
sensor capture, cloud credential, or device secret.

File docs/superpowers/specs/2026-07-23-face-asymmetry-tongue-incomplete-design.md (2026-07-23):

# Face Asymmetry and Tongue Incomplete Design

## Goal

Improve the ESP-WHO five-point face score for an upright face with one-sided
mouth-corner droop, and make an uncompleted tongue action explicit without
inventing a tongue score.

## Face F

The camera keeps the existing five-point order: left eye, left mouth corner,
nose, right eye, right mouth corner. Geometry derives three independent
signals normalized by eye distance: mouth-line angle relative to the eye line,
left/right mouth-corner height difference after eye-line compensation, and
nose-to-corner distance asymmetry. Each signal is converted to a descending
0..100 score. The frame F score is the minimum of these scores, then the
existing baseline/output median is applied. This keeps a focal mouth droop
visible even when one geometric signal is weak.

The algorithm remains a screening prompt, not a diagnosis. Head roll remains a
quality/repositioning failure, and no clinical accuracy is claimed.

## Tongue T

During the tongue stage, no tongue component remains `valid=false` after the
stage times out. The camera publishes `stage=error`; N16R8 keeps T unavailable,
so fusion excludes T instead of treating it as zero or a random value. The web
monitor displays `舌部动作未完成，T 未计入融合` for that incomplete result.

## Verification

- Add face regression coverage for a one-sided mouth-corner drop that lowers F.
- Add source/firmware coverage proving tongue timeout keeps T unavailable.
- Run focused tests, the full host suite, both ESP-IDF production builds, and
  real-device checks on camera COM9 and main COM3.

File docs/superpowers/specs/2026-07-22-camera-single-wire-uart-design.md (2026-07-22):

# Camera single-wire UART design

## Goal

Replace the unusable camera-to-main I2C link without adding hardware. The
camera coprocessor continues to perform local F/E/T perception. The N16R8
remains the Wi-Fi, MQTT, speech, CSI, fusion, and alarm controller. Raw images
remain local and never enter this link or the cloud.

## Wiring

- Camera GPIO48 (UART TX) -> N16R8 GPIO9 (UART RX)
- Camera SDA/GPIO47 remains disconnected
- Grounds remain connected
- Both boards keep independent USB power
- No board-to-board 5 V connection is used

UART0 on the camera remains reserved for the optional COM8 preview. The score
link uses UART1 at 115200 baud, 8 data bits, no parity, and 1 stop bit.

## Data protocol

The camera transmits a fixed-size binary packet five times per second. Each
packet contains:

- two-byte `SG` magic, protocol version, and packet length
- monotonically increasing sequence number
- F/E/T validity flags
- F score, signed mouth angle, and quality
- E score, signed eye detail, and quality
- T score, signed tongue offset, and quality
- guided stage and progress
- CRC16-CCITT over every byte except the CRC field

Only numeric perception results cross the link. The shared encoder and parser
live in `firmware_common` so both firmware projects use the same layout and CRC.
The main parser scans for magic, rejects unsupported versions or lengths,
rejects bad CRC packets, and resumes at the next possible magic sequence.

## Screening behavior

The camera runs the existing guided F/E/T session continuously. It automatically
starts a new cycle after boot and restarts after `done` or `error` with a short
cooldown. This is necessary because the one-way link cannot carry a start
command back to the camera.

The web start command still reaches the N16R8 over MQTT. It clears retained
speech and prior camera values, arms a new fusion session, and accepts fresh
camera packets. The UI displays the camera-reported stage and progress. A camera
cycle may already be in progress when the user clicks start; this is an explicit
initial-competition limitation, not a hidden synchronization guarantee.

## Failure handling

- No valid packet for two seconds marks F/E/T unavailable.
- Sequence gaps are logged but do not fabricate scores.
- CRC, version, and length failures are discarded.
- MQTT and CSI continue when the camera link is unavailable.
- Fusion remains `insufficient` when available modality weight is too low.
- This remains a risk prompt and care-seeking reminder, not a diagnosis.

## Verification

1. Unit-test packet round trips, CRC rejection, framing resynchronization, and
   timeout behavior.
2. Build both ESP-IDF projects with ESP-IDF v5.5.3.
3. Flash camera COM8 and main COM3.
4. Confirm the main logs fresh camera packets and non-null F/E/T values.
5. Publish a screening start command and confirm the main clears old state,
   accepts fresh scores, computes fusion, and uploads numeric data to the VPS.
6. Disconnect the GPIO48 link and confirm the system reports camera modalities
   unavailable rather than retaining or simulating them.

## Deferred options

Adding 4.7 kOhm pull-ups can restore the original bidirectional I2C design in a
later hardware revision. PC serial bridging is not part of the standalone demo.

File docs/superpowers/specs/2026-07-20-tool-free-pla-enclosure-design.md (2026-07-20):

# Tool-Free PLA Enclosure Design

## Goal

Replace all M3 assembly interfaces with low-deflection sliding and latching
features suitable for a preliminary PLA prototype. Correct the front-panel fit
and give the camera board and N16R8 equal-width locating guides.

## Five-Part Contract

The production set remains exactly five parts: shell, front panel, electronics
tray, rear cover, and desktop base. No screw, nut, insert, or separate printed
pin is required.

## Front Panel

The current panel exactly matches the shell opening and has no physical print
clearance. The replacement uses `0.6 mm` clearance on every edge. A fused front
retaining lip prevents the smaller panel from falling through the opening, and
four short rear stop tabs replace the full-height internal rails. The upper
tabs sit below the top edge so the panel can be tilted in from the rear and
seated without flexing the full shell.

## Electronics Tray

The camera board and N16R8 are physically reported to have the same `27 mm`
width. A shared open-ended guide channel therefore uses the approved `30 mm`
clear opening. The guides provide lateral location only; separate cable ties
through the existing tray slots retain each board. The antenna and connector
ends remain open. The NMO432 area is unchanged.

## Rear Cover

The cover slides downward in two shell-mounted side channels. The channels
carry service loads; one long in-plane PLA tongue near the lower side supplies
only the locking force and enters a shell pocket at the final position. The
tongue can be pressed inward by hand before the cover is slid upward. Tool-free
tray spacer ribs retain the electronics tray with the existing nominal gap and
do not apply spring pressure.

## Desktop Base

The body continues to enter the existing `7 degree` inclined socket. One rear
release tongue rises from an isolated pocket in the base and catches the lower
rear shell edge. The tongue uses a long thin PLA flexure and a sloped hook so it
can be pressed rearward by hand. The previous two screw holes and shell pilot
bosses are removed.

## Prototype Parameters

- panel edge clearance: `0.6 mm`;
- front retaining-lip overlap: `1.5 mm`;
- board-guide clear width: `30 mm`;
- rear slide-channel total running clearance: `0.5 mm`;
- rear-cover latch nominal engagement: `0.6 mm`;
- base latch nominal engagement: `0.5 mm`.

These values are starting dimensions for the next PLA print, not production
tolerances. Snap features should be operated only as needed during the
preliminary demonstration; repeated-cycle durability remains unmeasured.

## Validation And Reprint Scope

Automated tests must reject M3 holes and the old pressure-post/screw-boss
modules, verify all new retention modules and parameters, and retain the five
watertight single-component STL checks. The front-panel envelope must reflect
the new edge clearance. All five parts must be reprinted because each receives
either a fit, guide, rail, latch, or mating-interface change.

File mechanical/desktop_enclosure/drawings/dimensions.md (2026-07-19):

# Compact Desktop Enclosure Dimension Schedule

All dimensions are millimeters and nominal CAD values unless explicitly marked
as requiring a physical measurement.

## Main Envelope

| Feature | Nominal size |
| --- | ---: |
| Mirror body maximum | 110 x 165 x 40 mm |
| One-piece front panel | 104 x 159 x 2 mm |
| Rear cover | 102 x 157 x 2.4 mm |
| Desktop base slab | 110 x 65 x 12 mm |
| Rearward lean | 7 degrees |
| Nominal wall | 3.0 mm |

The base is outside the mirror-body envelope. The final assembled footprint
depends on the body angle and must be checked in the slicer and on the real
print.

## Camera And Electronics Tray

| Feature | Nominal size or constraint |
| --- | ---: |
| Camera aperture | 12 mm circular |
| Supplied camera module envelope | 27 x 42 x 19 mm |
| Camera-guide clear opening | 30 mm |
| Tray backplane | 96 x 149 x 3 mm |
| Tray total maximum envelope | 96 x 149 x 15 mm |
| Tray installed shift | 2 mm rearward from the original center plane |
| Rear-cover post nominal gap | 0.5 mm assembly gap |
| Moving fit clearance | 0.30 mm |
| Front-panel nominal clearance | 0.40 mm |

The camera drawing marks `4 mm` holes but does not provide complete mounting
coordinates. `electronics_tray.stl` therefore combines adjustable camera side
guides with cable-tie slots. N16R8 and NMO432 slots also avoid guessed board-hole
spacing. Shell stop pads set the tray's forward position; rear-cover pressure
posts retain it after the cover is installed.

## Fasteners

| Joint | Quantity | CAD interface | Length selection |
| --- | ---: | --- | --- |
| Rear cover to shell | 4 | 3.4 mm cover clearance into 2.6 mm printed pilot | Select after measuring the physical print |
| Mirror body to base | 2 | 3.4 mm base clearance into 2.6 mm reinforced pilot | Select after measuring the physical print |
| Camera module | As fitted | Tray side guides and cable ties | Match the supplied 27 x 42 mm board |
| N16R8 controller | As fitted | Repeated tray slots and cable ties | Match the actual controller board |
| NMO432 microphone | As fitted | Tray slots and cable ties | Match the actual microphone module |

M3 fasteners are mechanical additions, not sensors. The `2.6 mm` pilot is a CAD
starting point for thread-forming into printed plastic, not a guaranteed fit.
Board connector offsets, pilot/screw fit, print shrinkage, screw lengths,
material use, and stability require a physical print and measurement.

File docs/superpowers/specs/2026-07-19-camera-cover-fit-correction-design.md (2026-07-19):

# Camera And Rear-Cover Fit Correction Design

## Problem

The first physical print exposes two reproducible interferences:

- the camera module cannot enter the two side guides because their current
  `28.2 mm` nominal opening is too narrow for the real `27 mm` board after
  printing tolerance;
- the installed `19 mm` deep camera module reaches the front-panel retention
  area, while the rear-cover pressure posts extend about `4.8 mm` farther than
  the intended tray plane and prevent the cover from seating.

## Approved Geometry

- Set the camera-guide clear opening to `30 mm`.
- Continue using cable ties as the positive camera restraint; the guides only
  locate the module and do not rely on a press fit.
- Move the complete electronics tray from `Y=0 mm` to `Y=2 mm`, toward the rear
  cover, to recover front-panel clearance for the `19 mm` module depth.
- Recompute pressure-post length from the installed rear-cover inner face to
  the shifted tray plane and leave a nominal `0.5 mm` assembly gap.
- Keep the five-part production structure and all external dimensions.

## Validation

Tests must lock the `30 mm`, `2 mm`, and `0.5 mm` parameters, verify that the
pressure-post endpoint is derived from both rear-cover thicknesses, and retain
all existing watertightness, component-count, envelope, and unsupported-area
checks. OpenSCAD outputs and assembly renders must be regenerated.

Physical fit remains the final authority. The updated clearances are prototype
CAD values based on the reported first print and are not production tolerances.

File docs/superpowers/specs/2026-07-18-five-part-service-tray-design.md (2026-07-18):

# StrokeGuard Five-Part Service Tray Design

## Goal

Replace the three unattached internal parts with one removable electronics
tray so the compact enclosure has a complete, reproducible assembly path.

## Production Parts

The printable delivery contains exactly five parts:

- `compact_shell.stl`;
- `front_panel.stl`;
- `electronics_tray.stl`;
- `rear_cover.stl`;
- `desktop_base.stl`.

`camera_clamp.stl`, `controller_rail.stl`, and `microphone_holder.stl` are
removed from the production export after the replacement tray passes geometry
tests. User-created slicer projects, including untracked 3MF files, are not
deleted by this change.

## Electronics Tray

The tray uses a `96 x 149 x 3 mm` vertical backplane. Its complete printable
envelope, including the integrated camera cage and microphone supports, must
not exceed `96 x 149 x 15 mm`. It prints flat with the backplane on the build
plate and all retaining features facing upward.

The tray provides three zones:

1. A top camera cage for the documented `27 x 42 x 19 mm` module. Side guides,
   a central lens opening, and cable-tie slots constrain the board without
   guessed mounting-hole coordinates. The cage projects toward the front panel
   when installed and permits final lens alignment with the `12 mm` aperture.
2. A central universal N16R8 zone with repeated horizontal and vertical
   cable-tie slots. No controller-board dimensions or hole coordinates are
   encoded.
3. A lower NMO432 zone with repeated tie slots and an open path toward the
   front panel's lower acoustic notch. No microphone-board hole spacing is
   assumed.

Raw audio and video remain local; the tray contains no cloud, profile, or
credential data.

## Tray Retention

The canonical shell receives four fused tray stop pads around the installed
tray plane. The tray is inserted through the rear opening until it contacts the
front stops. Four rear-cover pressure posts contact the tray after the cover is
installed, sandwiching it between the stops and cover without a separate tray
fastener.

The stop pads and posts must overlap their parent printed parts by at least
`1 mm`; no isolated or merely coplanar solids are allowed. The tray, shell, and
rear cover must each export as one connected watertight mesh.

## Fastening

The preliminary prototype uses M3 screws directly in printed pilot holes:

- rear-cover clearance holes remain `3.4 mm`;
- matching shell pilot holes are `2.6 mm` nominal;
- base clearance holes remain `3.4 mm`;
- matching reinforced lower-shell pilot bosses are `2.6 mm` nominal.

The `2.6 mm` pilot is a starting CAD value for prototype plastic fastening, not
a measured guarantee. Screw length and pilot behavior must be checked on the
actual print and material. Do not force a screw toward a PCB or cable path.
Repeated production servicing may replace the pilot scheme with measured
heat-set inserts in a later hardware revision.

## Assembly

1. Insert `front_panel.stl` from the rear with the smooth face outward and the
   `12 mm` camera aperture at the top.
2. Secure the camera module, N16R8, and NMO432 to `electronics_tray.stl` with
   cable ties. Route camera I2C and microphone I2S separately and add strain
   relief.
3. Insert the populated tray from the rear until it seats against all four shell
   stops. Confirm lens and microphone alignment before closing the case.
4. Attach `compact_shell.stl` to `desktop_base.stl` with two M3 screws from the
   underside into the reinforced shell pilots.
5. Route power and debug cables through the lower rear exit.
6. Install `rear_cover.stl` with four M3 screws. Its pressure posts retain the
   electronics tray against the shell stops.

## Validation

Automated tests must verify:

- the export list and STL directory contain exactly the five production parts;
- the old three internal-part entry modes and STL files are absent;
- shell stops, rear-cover posts, and lower pilot bosses are present in source;
- the tray envelope is at most `96 x 149 x 15 mm`;
- tray, shell, rear cover, base, and front panel are watertight single-component
  meshes;
- printable orientation places each part on Z zero;
- no production STL contains a downward unsupported area larger than the
  documented test tolerance;
- assembled and exploded renders show the tray installed and separated;
- current README and dimension documents provide the exact five-part hardware
  relationship and no longer instruct users to assemble the three old parts.

Final verification requires OpenSCAD export and render, the complete mechanical
pytest suite, all 384 host tests, and `git diff --check`.

## Safety Boundary

StrokeGuard remains a risk-reminder and care-seeking aid, not a diagnostic
device. The mechanical redesign does not add hardware, make clinical claims,
or enable complex cloud instruction execution.

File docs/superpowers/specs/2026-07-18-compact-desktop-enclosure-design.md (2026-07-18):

# StrokeGuard Compact Desktop Enclosure Design

## Goal

Replace the oversized `214 x 300 x 55 mm` preliminary enclosure with a compact
desktop enclosure whose mirror body is no larger than `110 x 165 x 40 mm`.
The compact enclosure houses the ESP32-S3 N16R8 controller, the camera module,
and the NMO432 microphone without adding display, amplifier, LED, buzzer,
button, or other sensor provisions.

## Mechanical Authority

OpenSCAD remains the manufacturing source of truth. Generated STL and PNG
files are committed delivery artifacts. TinkerCAD is not authoritative for fit
or print dimensions. Dimensions not present in an approved drawing remain
adjustable and must not be inferred from photographs.

## Approved Envelope

| Feature | Approved nominal size |
| --- | ---: |
| Mirror body | `110 x 165 x 40 mm` maximum |
| Front panel | approximately `104 x 159 x 2 mm` |
| Camera aperture | centered circular `12 mm` diameter |
| Desktop base | `110 x 65 x 12 mm` |

The base is outside the mirror-body envelope. The assembled footprint may be
deeper than `40 mm` because the mirror leans rearward over the base. OpenSCAD
must calculate the final assembled footprint and the dimension schedule must
report it without claiming measured print performance.

## Camera Source Dimensions

The supplied module drawing defines the camera module as `27 x 42 x 19 mm` and
shows `4 mm` mounting holes. It does not provide a complete, unambiguous hole
spacing schedule. The compact camera clamp therefore uses side constraints and
cable-tie slots for a `27 x 42 mm` board and provides at least `19 mm` depth.
It must not encode guessed mounting-hole coordinates.

Only the lens is visible through the front panel. The previous `36 x 22 mm`
rectangular opening is replaced by a centered `12 mm` diameter circular
aperture. The camera board, connectors, and harness remain behind the panel.

## Printed Parts

The production export contains only these compact enclosure parts:

- `compact_shell.stl`: side, top, and bottom structure with open front and rear;
- `front_panel.stl`: one-piece front skin with the camera aperture and hidden
  lower microphone acoustic path;
- `rear_cover.stl`: removable service cover with a lower cable exit;
- `desktop_base.stl`: stable desktop foot and body locating interface;
- `camera_clamp.stl`: adjustable clamp for the documented camera envelope;
- `controller_rail.stl`: adjustable N16R8 support without guessed hole spacing;
- `microphone_holder.stl`: adjustable NMO432 support aligned to the hidden
  acoustic path.

The front panel is no longer split. Electronics are installed and serviced
from the rear. The rear cover remains removable after the body is seated in the
base.

## Removed Production Artifacts

The compact export replaces and removes these obsolete printable artifacts:

- `upper_shell.stl` and `lower_shell.stl`;
- `upper_rear_cover.stl` and `lower_rear_cover.stl`;
- `front_panel_upper.stl` and `front_panel_lower.stl`;
- the lower rear lap and center process-gap geometry;
- `camera_bezel.stl`;
- `usb_blank.stl`;
- `lean_support.stl`;
- the old `base.stl`, camera carriage, and fit coupon tied to the large model;
- old large-envelope display STL and renders, which are regenerated under the
  compact design.

Obsolete split-panel and large-enclosure handoff documents are removed after
their replacement documentation is committed. Their history remains available
in Git. Unrelated source directories are not deleted. Generated pytest caches
and mechanical temporary exports may be removed without staging them.

## Assembly

1. Print and test-fit the compact shell, front panel, rear cover, and base before
   installing electronics.
2. Seat the camera module in the adjustable clamp and align its lens with the
   `12 mm` aperture.
3. Mount the N16R8 on the adjustable controller rail while keeping its antenna
   area clear of fasteners and bundled wiring.
4. Mount NMO432 behind the hidden acoustic path and verify live microphone
   response after closing the enclosure.
5. Route camera I2C and microphone I2S separately, add strain relief, and route
   power and debug wiring through the rear lower cable exit.
6. Install the removable rear cover and seat the body in the desktop base.

## Validation

Automated mechanical tests must verify:

- the mirror body does not exceed `110 x 165 x 40 mm`;
- the camera aperture contract is circular and `12 mm` in diameter;
- the camera clamp accepts the documented `27 x 42 x 19 mm` envelope without
  relying on mounting-hole coordinates;
- every exported STL is watertight and fits a `220 x 220 mm` build plate;
- the export directory contains the compact production part list and no
  obsolete large-enclosure STL names;
- assembled and exploded renders are nonblank;
- documentation lists the exact print and assembly sequence.

Final verification consists of the complete mechanical pytest suite, the
existing 384 host tests, OpenSCAD export and render, and `git diff --check`.
Physical fit, print time, material use, dimensional shrinkage, thermal behavior,
and stability remain pending real prints and must not be presented as measured
results.

## Safety And Privacy Boundary

The enclosure does not change the product boundary: StrokeGuard is a health
risk reminder and care-seeking aid, not a diagnostic device. Raw audio and
video remain local and are not uploaded. The mechanical design adds no complex
cloud instruction execution or new sensing hardware.

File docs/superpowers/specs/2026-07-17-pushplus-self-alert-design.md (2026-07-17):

# PushPlus self-alert design

## Goal

Send a WeChat risk reminder to the PushPlus account that owns the configured
message token after StrokeGuard produces a warning or danger fusion result.

## Delivery contract

- Endpoint: `POST https://www.pushplus.plus/send` with JSON.
- Channel: `wechat`.
- Template: `markdown`.
- Recipient mode: self. The request includes neither `topic` nor `to`.
- A PushPlus `code` of `200` means the asynchronous request was accepted; it
  does not prove final WeChat delivery.
- The token owner must follow the PushPlus service account and complete the
  account requirements imposed by PushPlus, including real-name verification.

## Trigger policy

- Alerts are enabled only for an active guided screening session. A session is
  activated and reset by an accepted web `start` command or by a device
  transition into screening stage `1`.
- A web `cancel` command or device stage `7` deactivates the session. Stage `6`
  remains active so repeated completed-result uplinks can satisfy the warning
  confirmation rule.
- Backend restart does not infer an active session from an existing stage `6`
  uplink. The user or device must start a new screening.
- The first `danger` result in an active session sends immediately.
- `warning` sends only after three consecutive `warning` result uplinks in the
  same active session. `normal` or `insufficient` resets the consecutive count.
- Each session sends at most one warning alert and one danger alert. A later
  `warning` to `danger` escalation sends the danger alert even if the warning
  alert was already sent.
- Trigger only after valid fusion advice has been accepted for MQTT downlink.
  Counting warning uplinks must not generate extra LLM requests.
- Local sound/light alarms remain independent of cloud notification state.

## Message content

Include device ID, event time, F/S/T/E/CSI/final numeric scores, risk level,
the generated advice, and the non-diagnostic safety statement. Do not include
raw audio/video, MFCC, landmarks, eye trajectories, medication, conditions,
gender, age, phone number, or PushPlus token.

## Failure behavior

- Use a bounded HTTPS timeout and run the request outside the MQTT callback.
- Network, timeout, malformed JSON, and non-200 PushPlus codes are logged
  without token or message body.
- PushPlus failure must not block MQTT downlink, InfluxDB writes, the web page,
  or local alerts.
- Code `900` disables further attempts until process restart to avoid worsening
  an account request-limit restriction.

## Configuration

- `PUSHPLUS_ENABLED=1`
- `PUSHPLUS_TOKEN=<secret message token>`
- `PUSHPLUS_DEVICE_NAME=StrokeGuard Mirror 1` (optional)
- A PowerShell configurator reads the token with masked input and updates the
  untracked `cloud/.env` without writing the secret to transcripts.

## Verification

- Unit tests cover session activation and reset, three-warning confirmation,
  interruption by normal/insufficient, per-session limits, warning-to-danger
  escalation, request shape, response codes, timeout, and secret-free logs.
- Deployment first sends an explicit test message after user confirmation.
- End-to-end verification publishes a temporary warning fusion payload and
  confirms PushPlus returns an accepted message serial number.

## User prerequisites

1. Follow the PushPlus WeChat service account.
2. Complete PushPlus real-name verification if required by the account.
3. Create a dedicated message token on the one-to-one message page.
4. Enter the token only through the masked local configurator.
5. Approve one test notification during deployment.

## Official references

- https://www.pushplus.plus/push1.html
- https://www.pushplus.plus/doc/guide/api.html
- https://www.pushplus.plus/doc/guide/code.html

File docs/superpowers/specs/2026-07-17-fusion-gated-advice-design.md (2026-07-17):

# Fusion-gated AI advice

## Goal

Only generate and display AI advice after the device has produced a valid
fusion result. An advice remains visible for at most five minutes unless a new
guided screening starts first.

## Backend rules

- Every valid uplink is still cached and written to InfluxDB.
- An uplink with `level == "insufficient"` never schedules the advisor and
  never publishes an advice downlink.
- `normal`, `warning`, and `danger` uplinks may generate advice under the
  existing rate and newest-payload controls.
- Advice expires 300 seconds after its server generation timestamp.
- Starting screening through the web API immediately invalidates cached,
  pending, and in-flight advice from the previous screening.
- A device-originated transition into screening stage `1` applies the same
  invalidation, so the rule is not limited to the web button.
- An in-flight generation invalidated by a new screening must not be cached,
  published to MQTT, or written as current advice.

## Frontend rules

- The REST and WebSocket device responses omit expired or invalidated advice.
- When advice is omitted, the page displays `等待形成新的融合评分` and clears
  its source and generation time.
- Continuous `insufficient` uplinks do not hide an otherwise valid advice
  during its five-minute lifetime.

## Safety and privacy

The change does not alter the numeric-only cloud contract. Raw audio, images,
landmarks, MFCC arrays, and eye trajectories remain local. Advice remains a
risk reminder and does not represent a diagnosis.

## Verification

- `insufficient` uplinks perform no advisor call and no downlink publish.
- A valid fused uplink generates and exposes advice.
- The advice remains visible at 300 seconds and disappears after 300 seconds.
- Starting a new screening immediately hides old advice.
- An older in-flight generation cannot reappear after screening starts.

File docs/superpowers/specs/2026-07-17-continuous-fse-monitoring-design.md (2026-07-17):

# Continuous F/S/E Monitoring Design

## Goal

Make face (`F`), preliminary speech (`S`), and eye movement (`E`) continuously
available when their physical inputs are usable. Guided screening remains for
the higher-confidence center/left/right eye sequence and tongue extension.
The mirror continues to work without a PC, and raw audio/video remains local.

## User Experience

The authenticated web monitor defaults to `持续监测中`. F, S, and E update
without pressing Start. A missing or expired measurement displays `待采集`, not
zero. Start launches the existing guided F/E/T sequence; it does not start or
stop continuous S.

During a guided sequence the page retains the existing face, gaze, and tongue
instructions. A completed guided E result takes priority for 30 seconds. T is
still measured only during the tongue prompt. Cancel stops only the guided
camera sequence; continuous F/S/E continues.

## Face F

The camera coprocessor continues to produce F from ESP-WHO five-point geometry
whenever bbox and landmarks pass quality checks. The N16R8 stores the latest
valid F and mouth angle for five seconds after face loss. A new valid face
refreshes this timer.

After five seconds without a valid face, F becomes unavailable. A camera I2C
failure clears F immediately because transport failure cannot be treated as a
brief detector miss. The retained value is never presented as a new sample.

## Speech S

NMO432 capture and the preliminary acoustic engine run continuously after
audio initialization. The engine processes consecutive, non-overlapping
four-second windows. This keeps CPU and RAM bounded and produces a new result
often enough for the existing five-second score freshness limit.

Each window starts with local noise-floor estimation, then applies the existing
quality gates and heuristic features. A valid voiced window writes S with
`speech_veto_eligible=false`. A silent, too-short, too-quiet, clipped, or I/O
failed window clears the previous S instead of writing zero. The next window
starts automatically.

Continuous capture does not mean continuous storage. PCM blocks are consumed
in RAM and discarded. PCM, encoded audio, MFCC, FFT bins, voice embeddings,
and utterance fingerprints are prohibited from USB production frames, MQTT,
InfluxDB, logs, and LLM requests. Diagnostic logs contain only aggregate
quality values and bounded reason codes.

## Eye E

Whenever the camera has a current bbox and valid five-point landmarks, it runs
the existing pupil measurement for both eyes, independent of guided stage.
A bounded rolling tracker consumes valid measurements and estimates:

- average per-eye measurement quality;
- bilateral movement coherence;
- disagreement between left/right normalized displacement;
- temporal stability with brief blink tolerance;
- usable-sample ratio.

The continuous score is an initial tracking/coordination feature. It does not
measure visual fields and does not diagnose gaze palsy. Invalid landmarks,
implausible pupil regions, prolonged eye dropout, or insufficient rolling
samples make continuous E unavailable rather than healthy.

The existing center/left/right sequence remains the guided E algorithm. After
successful completion, its result overrides continuous E for 30 seconds. The
camera then returns to the rolling continuous result. Starting a new guided
session clears the previous guided override.

## Fusion Safety

Continuous F uses the existing face veto only while its five-second retained
sample is fresh. Preliminary S contributes to weighted fusion but cannot use
the speech single-item veto.

Continuous natural-eye E contributes to weighted fusion but cannot by itself
upgrade a normal result to warning. Guided E is also treated as an unevaluated
initial feature until measured validation exists; no sensitivity, specificity,
or clinical threshold claim is made. The existing final weighted formula is
unchanged.

T remains auxiliary and guided only. Arm weakness remains unmeasured by the
mirror.

## State And Interfaces

No raw-media or new cloud payload is introduced. The existing nullable numeric
fields remain authoritative:

```json
{"scores":{"face":null,"speech":null,"tongue":null,"eye":null,"csi":52,"final":0}}
```

The camera I2C score registers keep their existing sizes. Source precedence is
resolved on the camera board before E is encoded: a fresh guided result wins;
otherwise the continuous rolling result is returned. The N16R8 does not need a
new wire field to distinguish them because neither source is currently allowed
to trigger an E-only warning.

## Timing

- Camera polling remains 500 ms on the N16R8.
- F retention changes from two seconds to five seconds.
- S uses four-second non-overlapping windows and the existing five-second score
  freshness rule.
- Continuous E uses a bounded rolling window sized in valid samples, not
  unbounded history.
- Guided E overrides continuous E for 30 seconds.

These are engineering timing choices. End-to-end latency and score ranges are
reported only after hardware measurement.

## Failure Handling

- Camera transport failure: clear F/E/T immediately; S and CSI continue.
- Face detector miss under five seconds: retain F, but continuous E follows its
  own valid-sample/dropout rules.
- No speech in a four-second window: clear S and immediately begin the next
  window.
- Audio I/O failure: clear S, log a reason code, and retry capture without
  affecting camera or CSI tasks.
- Guided E/T failure: publish the existing screening error while continuous
  F/S/E continues; no failed guided value replaces a valid rolling result.
- Network outage: all local sensing and fusion continues; only numeric results
  are uploaded after MQTT reconnection.

## Testing

Unit tests cover five-second F retention and immediate transport clearing;
continuous speech auto-restart, valid update, and clearing after invalid
windows; rolling E quality, coherent motion, discordant motion, blink dropout,
and insufficient samples; guided E 30-second priority and expiry.

Integration tests verify continuous sensing without a start command, guided
camera controls do not stop S, no E-only warning is produced, score freshness
expires correctly, and cloud serialization remains numeric-only. Hardware
acceptance uses COM3/COM4 plus the VPS page to observe face enter/leave, quiet
and spoken audio windows, natural eye movement with bbox present, guided gaze,
and camera/audio disconnection.

## Medical Boundary

This product provides risk prompts and medical-attention reminders, not a
diagnosis. Sudden facial droop, unclear speech, one-sided weakness, visual or
balance changes, or altered consciousness requires calling 120 immediately,
regardless of device output. Continuous monitoring must not delay emergency
care or be described as clinical surveillance.

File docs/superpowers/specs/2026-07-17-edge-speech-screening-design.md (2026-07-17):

# Edge Speech Screening Design

## Goal

Add a preliminary FAST Speech (`S`) risk feature to the standalone N16R8
mirror using the installed NMO432 microphone. The implementation must work
without a PC, keep raw audio local, and remain explicit that it is an
unevaluated acoustic heuristic rather than a diagnostic model.

The guided phrase is `今天的天气很好`. The device measures whether a usable
utterance was captured and derives a repeatable acoustic clarity score. It
does not perform speech-to-text, identify the speaker, diagnose dysarthria, or
claim clinical sensitivity or specificity.

## Scope

Included:

- 16 kHz mono NMO432 capture on the N16R8.
- A bounded RAM audio window associated with one guided screening session.
- Signal-quality gating and low-cost time/frequency-domain features.
- A preliminary `speech` score and `p_clear` value for the existing score bus.
- Numeric-only MQTT uplink and existing web display.
- Unit, integration, privacy, and hardware acceptance tests.

Excluded:

- PCM, MFCC, spectrogram, or other raw/derived audio upload.
- Automatic speech recognition or phrase-content verification.
- CNN inference until a versioned, evaluated INT8 model exists.
- Clinical threshold calibration and medical-performance claims.
- MAX98357A playback; the web or existing local indication provides the prompt
  during this milestone.

## Architecture

`audio_nmo432` remains the sole I2S owner. It feeds fixed 20 ms blocks to a new
`speech_screening` component through an in-process function call. The speech
component owns session state, feature accumulators, quality gates, and result
generation. It never exposes PCM outside the firmware process.

The main controller starts speech capture when the camera coprocessor reaches
`SG_STAGE_DONE`. The speech stage lasts up to four seconds and waits for an
initial voiced region before accumulating an utterance. Completion writes a
valid result through `sg_score_bus_set_speech`; invalid capture leaves S
unavailable and records a retry reason. Cancellation resets all speech state
and buffered samples.

The existing camera stage protocol is not renumbered. Speech is represented by
main-controller session state only. No new MQTT field is added: clients infer
completion from whether the authoritative `scores.speech` value is present.

## Feature Pipeline

Audio is processed in 20 ms frames. Calculations use fixed-size buffers and
bounded accumulators suitable for ESP32-S3 RAM and CPU constraints.

1. Remove frame DC offset before feature calculations.
2. Compute RMS, peak, clipping ratio, and zero-crossing rate.
3. Estimate a startup noise floor from quiet frames with a bounded adaptive
   update.
4. Mark voice-active frames using energy above the noise floor plus hysteresis.
5. For active frames, accumulate:
   - voiced-frame ratio;
   - normalized short-time energy variation;
   - zero-crossing statistics;
   - low/mid/high band energy from a small fixed FFT or equivalent filter-bank;
   - spectral change between adjacent active frames;
   - pause and longest-contiguous-voice durations.

The implementation must be deterministic and saturate intermediate integer
operations. Floating point is acceptable for final normalization because the
ESP32-S3 has hardware floating-point support, but allocation is forbidden in
the per-frame path.

## Quality Gates

No S score is produced unless all quality gates pass:

- the I2S read stream is valid;
- clipping stays below the existing five-percent block limit;
- a minimum amount of voiced audio is present;
- the utterance is neither too short nor dominated by silence;
- signal level exceeds the measured noise floor by a configurable margin;
- enough valid frames exist to calculate every required feature.

Threshold constants are engineering defaults, not medical thresholds. They
must be named, documented, and changed only from measured local recordings.
Failed quality returns one stable reason such as `no_voice`, `too_short`,
`too_quiet`, or `clipped`; it does not return zero.

## Preliminary Score

Each accepted feature is normalized to `[0, 1]` and combined into
`p_clear`. The initial weighting emphasizes capture continuity and usable
speech dynamics while assigning smaller weight to spectral distribution.
`speech = round(100 * p_clear)` and both values are clamped to their contracts.

This score means "similarity to the locally defined clear-utterance acoustic
pattern," not probability of being medically normal. Until an evaluated model
replaces it:

- heuristic S participates in the weighted fusion only after quality passes;
- heuristic S must not trigger the speech single-item danger veto;
- the firmware version and local diagnostic log must identify the preliminary
  heuristic implementation;
- UI copy uses `初赛声学筛查`, not `CNN`, `诊断`, or `构音障碍检测`.

When a versioned evaluated model is later installed, its output can use the
existing speech-veto contract only after threshold validation.

## Data And Privacy

Only these speech-derived values may cross the device boundary under the
existing contract:

- `scores.speech`;
- the existing final score and level.

`p_clear` remains inside the local fusion input and is not added to MQTT.

PCM, encoded audio, MFCC arrays, FFT bins, utterance fingerprints, and voice
embeddings are prohibited from USB production frames, MQTT, InfluxDB, logs,
and LLM requests. Diagnostic logs may contain aggregate RMS, peak, frame counts,
and non-sensitive failure codes.

## Failure Handling

- Silence or invalid capture: leave S unavailable and ask for another reading.
- I2S timeout: abort the current speech capture without affecting F/T/E/CSI.
- User cancellation: clear active accumulators and publish no partial result.
- Network outage: local scoring and fusion continue; the latest numeric result
  can be uploaded after reconnection under existing MQTT behavior.
- Insufficient available fusion weight: retain the existing `insufficient`
  level rather than inventing a normal result.

## Testing

Host-side unit tests exercise the feature logic with deterministic synthetic
PCM fixtures: silence, low-level noise, speech-like multi-tone modulation,
continuous pure tone, clipping, short utterance, and interrupted utterance.
Tests verify availability decisions, stable failure reasons, score bounds, and
that speech-like input scores above invalid controls without asserting medical
accuracy.

Static privacy tests reject PCM, MFCC, FFT arrays, or encoded audio in cloud
serialization. Integration tests verify score-bus freshness, fusion without a
heuristic speech veto, cancellation, retry, and numeric-only MQTT output.

Hardware acceptance on COM3 compares quiet, normal near-field reading, and
far-field reading of the fixed phrase. Acceptance requires repeatable quality
gating, changing aggregate features, no resets, and no raw audio leaving the
device. Exact score ranges and latency will be measured after recordings are
collected under the final enclosure and microphone placement; the project must
not state values before that measurement.

## Medical Boundary

The feature supports FAST-style risk prompting but is not a diagnostic device.
Users must call 120 immediately for sudden facial droop, unclear speech,
one-sided weakness, visual or balance changes, or altered consciousness,
regardless of the device result. Arm weakness is not independently measured by
the mirror. Tongue analysis remains auxiliary only.

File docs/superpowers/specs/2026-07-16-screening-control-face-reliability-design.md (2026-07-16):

# Screening Control and Face Reliability Design

## Goal

Make guided screening start reliably under continuous I2C polling and make the
F stage tolerant of ordinary detection jitter without inventing a healthy
score. This is an initial-competition reliability change, not a diagnostic
performance claim.

## Confirmed Failure

The public web command reached the N16R8 as an MQTT control downlink, but the
camera stage remained idle. The camera target currently sends register-select,
read-request, and screening-control events through the same eight-item queue.
Continuous polling can fill that queue, and callback enqueue failures are not
reported. A start command can therefore be lost before face processing begins.

## I2C Control Design

The camera I2C receive callback handles a valid two-byte control write as a
separate bounded latch. It does not enqueue that write with ordinary register
traffic. The latch stores only the latest `start` or `cancel` action and is
consumed by the camera application loop. Register selection and read requests
retain their existing queue and response protocol.

The N16R8 records a pending control after a successful I2C write. It confirms
success only after the polled stage changes to the expected state:

- `start` expects `FACE`;
- `cancel` expects `IDLE`;
- confirmation is bounded and retried a small fixed number of times;
- failure leaves scores unavailable and logs an error without credentials or
  biometric data.

The MQTT, I2C register, and numeric uplink contracts remain unchanged.

## Face Stage Design

F remains based on ESP-WHO five-point landmarks and a volatile personal neutral
baseline. A frame is eligible only when it has one selected face, valid five
points, acceptable geometry quality, and a sufficiently large frontal face.

The detector uses balanced proposal/landmark thresholds of `0.40` and `0.45`.
The stage requires at least two eligible samples in the latest five sampled
frames rather than merely elapsed wall time. Its overall deadline is 20 seconds
so an absent face cannot leave screening running indefinitely. Stable
eligible samples feed the existing median/baseline path; invalid or stale input
clears F instead of emitting `100`.

The preview may retain the last bbox for at most two missed frames to avoid
visual flicker. A retained bbox is display-only and never makes landmarks,
baseline input, or F valid.

The F result must continue to change with measured relative mouth geometry.
No score is produced from a bounding box alone, and no fallback constant is
allowed.

## Status and Diagnostics

The camera logs bounded, non-biometric reason counters for rejected F samples:
no face, invalid landmarks, geometry quality, or baseline pending. It logs
control receipt and stage transitions. The N16R8 logs control confirmation or
bounded failure.

The existing public stage value remains the wire contract. The web UI maps
active F progress to concise prompts such as detecting face, aligning face, and
building baseline when that information is locally available; otherwise it
uses the existing F-stage prompt. A terminal error never displays a numeric F.

## Privacy and Medical Boundaries

Images, bounding boxes, landmarks, baseline geometry, and rejection details
remain on the camera/N16R8. MQTT, InfluxDB, the VPS, and the LLM receive only
numeric scores, availability, stage, level, profile fields already permitted by
the contract, and advice text. F is a risk-screening signal, not a diagnosis.

## Tests

Host tests cover:

- control writes bypass the ordinary event queue and latest action wins;
- start/cancel confirmation retries are bounded;
- F requires two eligible samples in a five-frame window;
- intermittent invalid frames do not create a score;
- no face reaches error at the overall deadline;
- stale F is cleared and never defaults to `100`;
- cloud payloads remain numeric-only.

Target verification builds both firmware projects, flashes COM4 then COM3, and
checks: MQTT control reception, camera `FACE` acknowledgement, visible stage
progress, changing F from real landmarks, failure with the lens obscured, and
continued CSI/MQTT operation.

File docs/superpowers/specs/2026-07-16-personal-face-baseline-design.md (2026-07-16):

# Personal Face Baseline Design

## Goal

Make the camera-side FAST Face risk feature respond to visible mouth changes
in real time by comparing each user with a short-lived neutral baseline. The
baseline and all landmarks remain in camera RAM and are never uploaded.

This is a personalized engineering change indicator, not a diagnosis or a
validated probability of stroke.

## State Machine

The camera owns three states:

1. `WAITING`: no usable face; F is unavailable.
2. `CALIBRATING`: collect five consecutive high-quality neutral samples; F is
   unavailable and does not enter fusion.
3. `READY`: score each valid frame relative to the stored baseline and publish
   a rolling three-frame median.

Any failed geometry gate during calibration clears the calibration window.
In `READY`, short invalid gaps retain the baseline but do not publish new F.
Ten continuous seconds without valid geometry clears the baseline and returns
to `WAITING`, so a new user receives a new baseline.

## Baseline Acceptance

Every calibration sample must have geometry quality at least 70. Five samples
are accepted only when their mouth-angle range is at most 2 degrees and their
corner-asymmetry range is at most 0.03. The baseline is the median mouth angle
and median corner asymmetry of those samples.

The baseline is volatile. It is not written to flash, NVS, logs, MQTT,
InfluxDB, or the LLM request.

## Relative Score

For each valid frame in `READY`:

```text
angle_delta = abs(frame_angle - baseline_angle)
asymmetry_delta = abs(frame_asymmetry - baseline_asymmetry)
```

The angle subscore is 100 at `angle_delta <= 0.5` degrees, 0 at
`angle_delta >= 8` degrees, and linear between those limits. The distance
subscore is 100 at `asymmetry_delta <= 0.01`, 0 at
`asymmetry_delta >= 0.15`, and linear between those limits.

```text
F = round(0.75 * angle_subscore + 0.25 * distance_subscore)
```

The published result is the median of the latest three valid relative scores,
signed absolute mouth angles, and quality values. The existing absolute mouth
angle remains on the wire so the `abs(angle) > 20` danger veto is unchanged.
The expected response time is approximately 1–2 seconds and must be reported
as measured rather than guaranteed.

## Interfaces

The four-byte I2C register `0x02` remains unchanged:

```text
[status, relative_F_score, signed_absolute_mouth_angle, quality]
```

`status=0` covers waiting, calibration, invalid geometry, and stale output.
`status=1` means a stable relative score is available. No raw baseline or
landmark values cross I2C.

The cloud numeric contract remains unchanged. Before readiness, `face` is
`null`; after readiness, it is the relative score. Speech, tongue, and eye
remain unavailable in this increment.

## Safety And Limitations

- The user must look naturally at the camera during initial calibration.
- Starting with a deliberately asymmetric expression can create a misleading
  baseline; the mirror must prompt the user to relax and face forward.
- Five-point landmarks are designed primarily for alignment and remain less
  sensitive than an evaluated dense-landmark model.
- Lighting, expression, pose, occlusion, and natural asymmetry can affect the
  score.
- A user with FAST symptoms should call emergency services immediately and
  must not wait for calibration or rely on the score.

## Verification

Automated tests cover baseline sample count, quality rejection, stability
range rejection, median baseline values, relative score boundaries,
three-frame median behavior, brief invalid gaps, and ten-second reset.

Hardware acceptance has three measured phases with one user and fixed camera
position:

1. Natural frontal face until baseline becomes ready.
2. Deliberately lower one mouth corner and verify F changes materially within
   the measured response interval.
3. Return to the natural expression and verify F moves back toward its
   baseline range.

COM3 and VPS must report numeric values from the same phase. No target score
range is claimed before measured behavior is observed.

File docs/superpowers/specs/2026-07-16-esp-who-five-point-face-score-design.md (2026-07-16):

# ESP-WHO Five-Point Face Score Design

## Goal

Add a real, locally computed FAST Face (F) risk feature to the camera
coprocessor. The feature uses the five landmarks already produced by the
ESP-WHO face detector, sends only numeric results to the N16R8 controller,
and never uploads images or landmarks.

This is a preliminary-contest engineering risk indicator. It is not a
diagnosis of facial palsy or stroke, and its thresholds require later
calibration with consented samples and K-fold evaluation.

## Scope

This increment implements F only. Speech (S), auxiliary tongue deviation
(T), and eye movement (E) remain unavailable until their own reviewed
increments. The existing face bounding-box preview and I2C register remain
available for debugging.

## Architecture

The GC2145 camera board remains the owner of all image processing. For the
largest detected face, it reads ESP-DL's MNP landmarks in their actual tensor
order: left eye, left mouth corner, nose tip, right eye, right mouth corner.
A focused geometry module validates the landmarks, computes face asymmetry,
and feeds a five-sample temporal median. The camera I2C target exposes the
stable numeric result to the N16R8 controller.

The N16R8 polls the numeric F register, validates the response, and calls the
existing `sg_score_bus_apply_camera()` interface. It uses the absolute mouth
angle because the existing fusion veto compares angle magnitude. Invalid or
stale observations reset F to unavailable rather than substituting a healthy
score.

## Landmark Quality Gate

An observation is valid only when all of these checks pass:

- exactly five landmark pairs are available;
- the selected face width is at least 64 pixels in the 320x240 frame;
- inter-eye distance is at least 20 pixels;
- both mouth corners and the nose tip are inside the selected face box;
- the nose horizontal position lies within the middle 50% of the eye span;
- the mouth midpoint lies below the eye midpoint;
- the absolute eye-line roll is at most 25 degrees.

Failure of any check produces an unavailable F observation. These limits are
initial engineering values and must be exposed as named constants, not
presented as validated medical thresholds.

## Geometry And Score

The geometry module computes:

1. `eye_angle = atan2(right_eye.y - left_eye.y, right_eye.x - left_eye.x)`.
2. `mouth_angle = atan2(right_mouth.y - left_mouth.y,
   right_mouth.x - left_mouth.x) - eye_angle`, normalized to `[-90, 90]`.
3. `corner_asymmetry = abs(distance(nose, left_mouth) -
   distance(nose, right_mouth)) / (distance_left + distance_right)`.

The angle subscore is 100 at `abs(mouth_angle) <= 2` degrees, 0 at
`abs(mouth_angle) >= 20` degrees, and linearly interpolated in between. The
distance subscore is 100 at `corner_asymmetry <= 0.05`, 0 at
`corner_asymmetry >= 0.35`, and linearly interpolated in between.

The frame score is:

```text
F = round(0.75 * angle_subscore + 0.25 * distance_subscore)
```

The camera retains the latest five valid frame scores and signed mouth
angles. It publishes the median score and median angle only after five valid
samples. A failed quality gate clears the accumulation so samples from
different face presentations are not mixed. Score and quality are bounded to
`0..100`; signed angle is rounded and saturated to `-90..90` degrees.

## I2C Protocol

The slave address remains `0x52`.

- Register `0x01` remains the four-byte bbox response
  `[center_x, center_y, width, height]`.
- Register `0x02` is the four-byte F response
  `[status, score, signed_angle_i8, quality]`.

`status=1` means the remaining fields are valid. `status=0` means F is
unavailable and the other bytes must be ignored. `quality` is an engineering
quality score derived from face size, eye distance, and pose margins; it is
for observability and does not enter medical fusion in this increment.

All protocol structs are packed and statically asserted to four bytes. The
shared protocol parser rejects wrong lengths, unknown status values, scores
above 100, quality above 100, and angles outside `-90..90`.

## Fusion And Safety

The N16R8 applies a valid response with:

```c
sg_score_bus_apply_camera(true, score, fabsf(angle_deg),
                          false, 0, false, 0, now_us);
```

The existing fusion behavior remains authoritative: `face < 30` or absolute
mouth angle above 20 degrees can trigger the danger veto. The device must not
derive tongue or eye scores from the five face landmarks in this increment.

Five-point geometry is sensitive to natural facial asymmetry, expression,
camera pose, occlusion, and detector error. The UI and documentation continue
to describe the result as a risk prompt and care-seeking reminder. A user with
FAST symptoms should call emergency services immediately and must not wait for
or rely on the device score.

## Error Handling

- No face or failed quality gate: clear the five-frame accumulator and expose
  `status=0`.
- Malformed I2C response: N16R8 marks F unavailable and logs a bounded warning.
- Camera response older than the existing stale timeout: F becomes
  unavailable.
- I2C failure: local CSI and other available modalities continue operating.
- USB preview remains request-gated and local; no new image transport is
  introduced.

## Verification

Automated verification covers:

- level eyes and level mouth produce a high score;
- mouth-corner displacement lowers the score and reports the expected signed
  angle;
- equal head roll applied to eyes and mouth is removed by roll correction;
- side-pose, small-face, incomplete-landmark, and invalid geometry cases are
  rejected;
- five-sample median suppresses one outlier and resets after an invalid frame;
- register `0x01` remains backward compatible;
- register `0x02` encoding and parsing reject malformed values;
- N16R8 publishes a valid F score and leaves S/T/E unavailable;
- both ESP-IDF projects build and the complete host test suite passes.

Hardware acceptance uses COM4 camera logs and COM3 controller logs. With a
well-lit frontal face held steady for five valid frames, COM3 must report a
numeric F score and signed mouth angle. Removing the face must return F to
unavailable after the existing stale interval. Threshold accuracy,
sensitivity, and specificity remain pending measured evaluation.

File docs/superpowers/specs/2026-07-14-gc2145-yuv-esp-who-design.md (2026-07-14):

# GC2145 YUV ESP-WHO Design

## Decision

The GC2145 does not support native JPEG output in `esp32-camera`. Capture
QVGA YUV422 instead, convert each requested frame to RGB888 in local PSRAM,
and pass that RGB888 image to ESP-WHO `HumanFaceDetect`.

## Data Flow

1. GC2145 captures `320x240` YUV422 into a camera frame buffer.
2. `fmt2rgb888` converts the frame into one reusable PSRAM buffer.
3. ESP-WHO consumes `DL_IMAGE_PIX_TYPE_RGB888` and emits a normalized bbox.
4. On an explicit USB preview request, `frame2jpg` encodes the original YUV
   frame and sends it only to the directly attached PC.
5. I2C continues to expose only the four-byte bbox at `0x52/0x01`.

## Failure And Privacy Rules

- Allocation or conversion failure produces no bbox and an error log.
- Raw image buffers never enter Wi-Fi, MQTT, VPS, or large-model payloads.
- USB preview remains request-gated, transient, and local.
- A face bbox is not a FAST facial-asymmetry score or medical diagnosis.

## Acceptance

- Firmware builds with ESP-IDF 5.5.3 for ESP32-S3.
- COM4 preview has coherent geometry without repeated horizontal sections.
- A visible face produces an ESP-WHO bbox in the preview and I2C response.

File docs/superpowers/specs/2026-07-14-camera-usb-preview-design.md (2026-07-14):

# Camera USB Preview Design

## Goal

Provide a local debugging view of the GC2145 camera on the PC while the
camera coprocessor continues ESP-WHO face detection and I2C communication
with the N16R8 main controller.

The preview is a development aid. It is not part of the medical risk score
and must not upload or persist raw images.

## Scope

- Camera board: Hiwonder ESP32-S3-Cam N8R8 with GC2145 on COM4.
- Main board: ESP32-S3 N16R8 remains connected over I2C address `0x52`.
- PC: standalone Python preview tool using the existing host virtual
  environment.
- Transport: local UART through the camera board CH340 USB adapter.

VPS forwarding, browser streaming, recording, screenshots, and cloud storage
are out of scope.

## Runtime Design

The camera acquisition loop remains the only owner of `camera_fb_t`. It runs
ESP-WHO first, updates the latest face bounding box for I2C, and services at
most one pending PC preview request before returning the frame buffer.

The PC controls the preview rate by sending a request byte. The camera board
does not stream unless a tool is connected and requests a frame. RGB565 is
converted to JPEG only for the requested frame, limiting extra CPU and UART
load.

The preview tool requests the next frame only after the previous response is
validated and displayed. This provides natural backpressure and avoids a
second frame queue on the camera board.

## Serial Protocol

UART settings are `921600 8N1`.

PC request:

```text
0xA5
```

Camera response, little-endian fields:

```text
magic[4] = "SGJP"
version:u8 = 1
flags:u8
header_size:u16
sequence:u32
jpeg_length:u32
center_x:u8
center_y:u8
width:u8
height:u8
jpeg[jpeg_length]
crc32:u32
```

The CRC covers the fixed header after `magic`, followed by the JPEG payload.
The four bounding-box bytes use the existing normalized 0-255 camera protocol;
all zero means no face.

The PC parser scans for `SGJP`, validates version, size limits, JPEG markers,
and CRC, then recovers by scanning for the next magic value after malformed or
partial data. Maximum accepted JPEG size is 128 KiB.

## Console Interaction

Normal boot diagnostics remain at 115200 until the preview UART service is
initialized, then UART0 switches to 921600. The PC tool owns COM4 while open.
It shows protocol and firmware errors in its own status area; a second serial
monitor must not open COM4 concurrently.

## PC Tool

`host_pc/tools/camera_usb_preview.py` provides:

- COM port selector, defaulting to COM4 when present.
- Connect/disconnect controls.
- Live image without recording.
- Face bounding-box overlay from the camera response.
- FPS, JPEG size, frame sequence, and connection status.
- Clear offline and CRC/protocol error states.

The tool uses PyQt5, pyserial, and Pillow already available through the host
project dependency workflow. Closing the window releases COM4 immediately.

## Privacy And Medical Boundary

- JPEG bytes travel only from the camera board to the directly connected PC.
- The tool does not save images or send network requests.
- The VPS, MQTT, InfluxDB, and large-model service receive no image data.
- A detected face box is not a FAST face-asymmetry score and is never converted
  into an F score by this feature.

## Failure Handling

- No COM4: show offline and allow refresh/reconnect.
- Timeout: retain the last frame with a disconnected/stale indicator.
- Bad length, JPEG, or CRC: discard the frame and resynchronize.
- JPEG conversion failure: camera returns an error flag with no payload.
- PC disconnect: no new request arrives, so preview work stops automatically.
- I2C and ESP-WHO continue even when USB preview is unavailable.

## Verification

- Unit tests cover request parsing, response framing, CRC rejection, partial
  reads, resynchronization, and the no-save/no-network privacy boundary.
- Camera firmware and N16R8 firmware both build with ESP-IDF 5.5.3.
- On hardware, COM4 displays changing GC2145 frames and a face overlay when
  ESP-WHO reports a bounding box.
- COM3 continues to log `camera coprocessor online addr=0x52 reg=0x01` during
  preview.
- Closing the tool stops preview requests while face detection and I2C remain
  operational.

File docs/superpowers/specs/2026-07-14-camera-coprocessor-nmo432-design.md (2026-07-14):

# ESP32-S3 Camera Coprocessor and NMO432 Design

## Scope

The preliminary-demo device uses two ESP32-S3 boards:

- The existing ESP32-S3-WROOM-1 N16R8 board remains the StrokeGuard main controller.
- The Hiwonder ESP32-S3-Cam board and its expansion board form a camera coprocessor.
- The NMO432 digital microphone connects directly to the N16R8 main controller.

ST7789, MAX98357A, RGB LED, buzzer, and buttons are outside this phase. The
camera product is not a raw GC2145 module and must not be described or driven as
one. Its published material identifies a self-contained ESP32-S3 camera module;
the exact image sensor remains unverified.

## Architecture

```text
ESP32-S3-Cam camera coprocessor
  - local image capture
  - image quality checks
  - future local F/T/E inference
             |
             | I2C: structured values only
             v
ESP32-S3-WROOM-1 N16R8 main controller
  - NMO432 audio capture and future S inference
  - Wi-Fi CSI auxiliary stability score
  - five-modal fusion and veto rules
  - Wi-Fi/MQTT uplink and advice downlink
```

Continuous JPEG transfer is not part of the production path. The camera
module's Type-C/UART connection is reserved for flashing, logs, and optional
single-frame development diagnostics.

## Wiring Allocation

The proposed N16R8 signal allocation avoids the boot-strapping pins and keeps
the camera and microphone buses separate:

| Function | Peripheral pin | N16R8 pin |
| --- | --- | --- |
| Camera I2C data | SDA | GPIO8 |
| Camera I2C clock | SCL | GPIO9 |
| Camera power | 5V | 5V supply rail |
| Camera ground | GND | GND |
| NMO432 bit clock | SCK | GPIO17 |
| NMO432 word select | WS | GPIO18 |
| NMO432 sample data | SD | GPIO16 |
| NMO432 power | VDD | 3.3V |
| NMO432 ground | GND | GND |

The camera expansion-board I2C connector order must be checked against its
silkscreen or vendor schematic before power is applied. The NMO432 L/R pin must
be tied to GND or 3.3V according to the channel selected in firmware. All boards
must share ground. The camera module's documented input supply is 4.75-5.25 V;
its I2C GPIO logic is expected to be 3.3 V but must be verified before wiring.

## I2C Contract

The N16R8 is the I2C controller and the camera module is target address `0x42`.
The controller reads the fixed-size version 1 frame every 500 ms. Multi-byte
fields are little-endian.

```c
typedef struct __attribute__((packed)) {
    uint8_t version;          // Always 1 for this layout
    uint8_t sequence;         // Increments after each completed inference
    uint8_t face;             // 0-100 when valid
    uint8_t tongue;           // 0-100 when valid
    uint8_t eye;              // 0-100 when valid
    uint8_t quality;          // 0-100 image quality
    uint8_t valid_mask;       // bit0=F, bit1=T, bit2=E
    uint8_t status;           // ready, busy, no_face, or error
    int16_t mouth_angle_x10;  // Signed degrees multiplied by 10
    uint16_t latency_ms;      // Last completed processing latency
    uint16_t crc16;           // CRC-16 over all preceding bytes
} camera_scores_v1_t;
```

The status numeric values and CRC parameters will be defined in a shared header
used by both firmware projects. A protocol-version mismatch is an unavailable
camera result, not a score of zero.

## Data and Privacy

- Raw images remain on the camera module or a directly attached local
  development computer.
- Raw audio remains on the N16R8 or a directly attached local development
  computer.
- MQTT and the VPS receive only scores, quality/status metadata, profile data,
  fused level, reasons, and model-generated advice.
- The cloud model never receives images, audio, or MFCC arrays.

## Failure Handling

- No face, poor exposure, a missing model, or incomplete inference clears the
  corresponding validity bit. It must not emit a fabricated normal or zero
  score.
- Repeated I2C failures mark the camera coprocessor offline. NMO432, CSI,
  networking, and device management continue to run.
- Reconnection is automatic after valid version and CRC frames resume.
- Missing F/T/E produces fusion level `insufficient`; it cannot produce a
  misleading complete risk score.
- The device remains a risk-prompt and medical-attention reminder product, not
  a diagnostic device. Arm weakness is not independently measured.

## Delivery Order

1. Confirm the camera expansion-board I2C connector order and logic voltage.
2. Obtain or build the camera-module firmware project and establish local image
   capture plus diagnostic logs.
3. Implement the shared I2C frame on the camera target and N16R8 controller.
4. Implement NMO432 16 kHz mono capture on N16R8 with signal-quality metrics.
5. Integrate real F/T/E and S models only after versioned weights and evaluation
   data are available.
6. Feed validity-aware scores into the existing fusion and MQTT path.

No medical accuracy is claimed before representative data evaluation. Latency,
frame rate, current draw, and I2C reliability remain measurements to be recorded
on the actual hardware.

## First-Stage Acceptance

- Both boards run continuously for 30 minutes without reset or buffer growth.
- N16R8 receives valid CRC frames with increasing sequence values.
- Disconnecting the I2C cable marks the camera offline without stopping audio,
  CSI, Wi-Fi, or MQTT tasks.
- Reconnecting restores camera communication without rebooting N16R8.
- Missing models and invalid images never produce fabricated F/T/E scores.
- Raw images and audio are absent from MQTT payloads and VPS storage.

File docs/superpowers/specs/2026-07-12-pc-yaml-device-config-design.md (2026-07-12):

# PC YAML and ESP32-S3 Configuration Design

## 1. Objective

StrokeGuard keeps the ESP32-S3 as the authoritative runtime device while
allowing the optional PyQt5 PC application to edit a local YAML profile and
synchronize an explicitly bounded subset to the mirror over the local network.
Closing the PC, losing the LAN, or submitting an invalid configuration must not
interrupt local sensing, fusion, display, or alarms.

This feature does not make the PC a score producer and does not restore the old
PC-to-device score injection path.

## 2. Chosen approach

The PC owns YAML parsing and editing. It converts validated YAML fields to a
strict JSON request for the device. The ESP32-S3 does not parse YAML.

This keeps YAML usability in the management application without adding a YAML
parser or arbitrary document handling to firmware. USB-CDC remains a recovery
and diagnostic interface; normal configuration uses the LAN API.

## 3. Local YAML contract

The local file remains `host_pc/config/profile.yaml` and uses this versioned
shape:

```yaml
schema_version: 1
device_id: sg-0001

device:
  host: strokeguard-sg-0001.local
  port: 80

user:
  age: 68
  gender: M
  conditions:
    - hypertension
  meds:
    - aspirin
  stroke_history: false

thresholds:
  face_danger: 30
  mouth_angle_danger_deg: 20
  speech_danger: 35
```

Rules:

- The file is UTF-8 and no larger than 64 KiB.
- Unknown fields are rejected rather than ignored.
- `device_id` is limited to `[A-Za-z0-9_-]` and 32 characters.
- `host` accepts a private/link-local IP address or a `.local` hostname. The PC
  refuses to send the management credential to a public destination.
- Age is `0..130`; gender is `M`, `F`, or `other`.
- Conditions and medications each contain at most four non-empty strings of at
  most 31 UTF-8 characters.
- `thresholds` is an optional read-only release baseline. Omitting it restores
  the release values. Any different value fails validation and is never sent
  to the device.
- Wi-Fi, MQTT, VPS, and LLM credentials never appear in YAML.
- Legacy files without `schema_version` and `device` are loaded as version 0,
  validated, migrated in memory, and written as version 1 only after an
  explicit save.

Saving is atomic: write a temporary file in the same directory, flush it,
replace the target, and leave the previous file intact on failure.
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

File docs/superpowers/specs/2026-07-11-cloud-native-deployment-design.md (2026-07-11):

# 卒中卫士云端原生部署设计

日期：2026-07-11

> 架构更新：本文件只描述云端部署。运行时 uplink 发布者已由 PC 改为 ESP32-S3；系统边界以 [独立镜端架构设计](2026-07-11-standalone-edge-mirror-design.md) 为准。

## 目标

在当前受限 Ubuntu 22.04 云容器中部署 EMQX、InfluxDB 和 FastAPI，保持 M5 数据契约不变，不依赖 Docker、systemd 或容器特权能力。所有部署脚本、配置模板和运行数据入口位于项目的 `cloud/native/` 目录。

## 环境结论

当前云环境的 PID 1 为 `tini -- sleep infinity`，根文件系统为 overlay，并缺少 `CAP_SYS_ADMIN` 与 `CAP_NET_ADMIN`。Docker 守护进程无法创建 NAT/iptables 规则，因此 Docker Compose 方案保留但不用于该环境。

## 方案

采用项目内自包含运行时：

- EMQX 5.7.2 使用官方 Ubuntu 22.04 amd64 发行包，安装到 `cloud/native/runtime/emqx/`。
- InfluxDB 2.7.11 使用官方 Linux amd64 发行包，安装到 `cloud/native/runtime/influxdb/`。
- FastAPI 使用 Python 3 venv，安装到 `cloud/native/runtime/venv/`。
- 持久数据放在 `cloud/native/state/`，日志放在 `cloud/native/logs/`，PID 文件放在 `cloud/native/run/`。
- 生成目录全部加入 `.gitignore`，仓库只保存脚本、模板和文档。
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

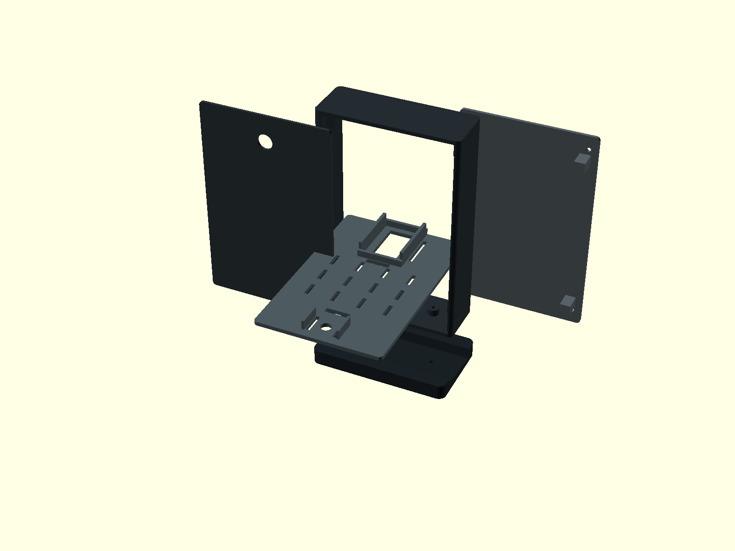
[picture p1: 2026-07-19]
mechanical/desktop_enclosure/renders/exploded.png

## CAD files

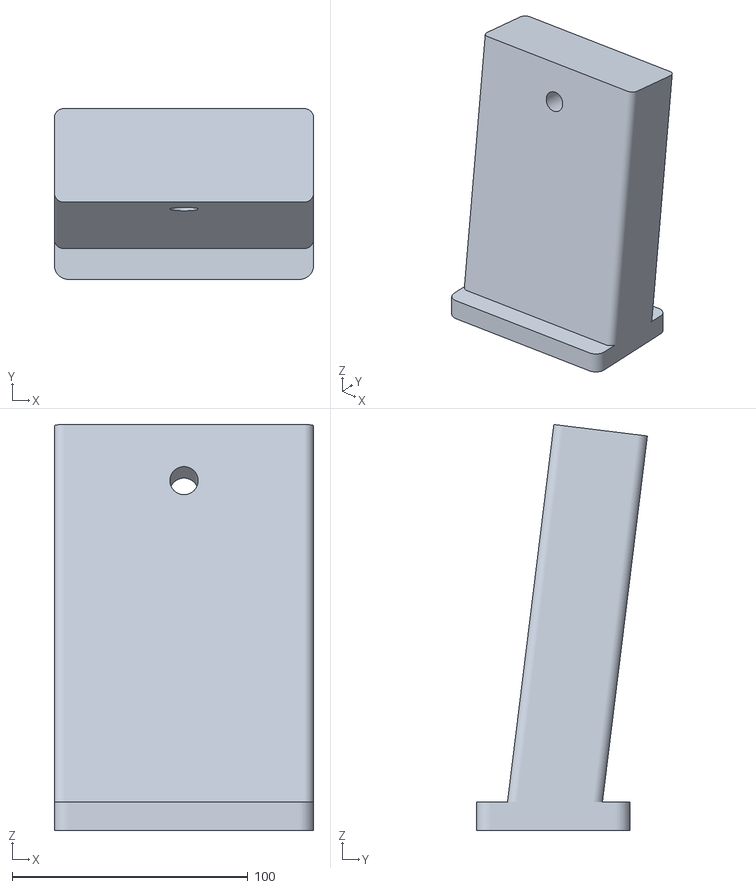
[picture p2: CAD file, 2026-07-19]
mechanical/desktop_enclosure/stl/display/strokeguard-display.stl
110.0 x 72.5 x 172.2

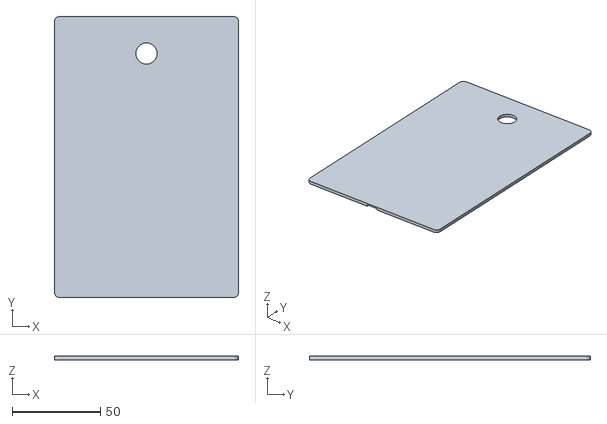
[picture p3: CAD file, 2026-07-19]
mechanical/desktop_enclosure/stl/printable/front_panel.stl
104.0 x 159.0 x 2.00

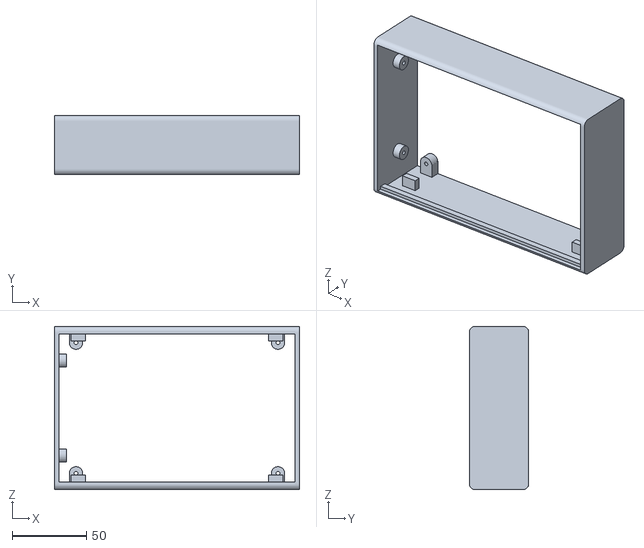
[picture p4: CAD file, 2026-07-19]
mechanical/desktop_enclosure/stl/printable/compact_shell.stl
165.0 x 40.0 x 110.0

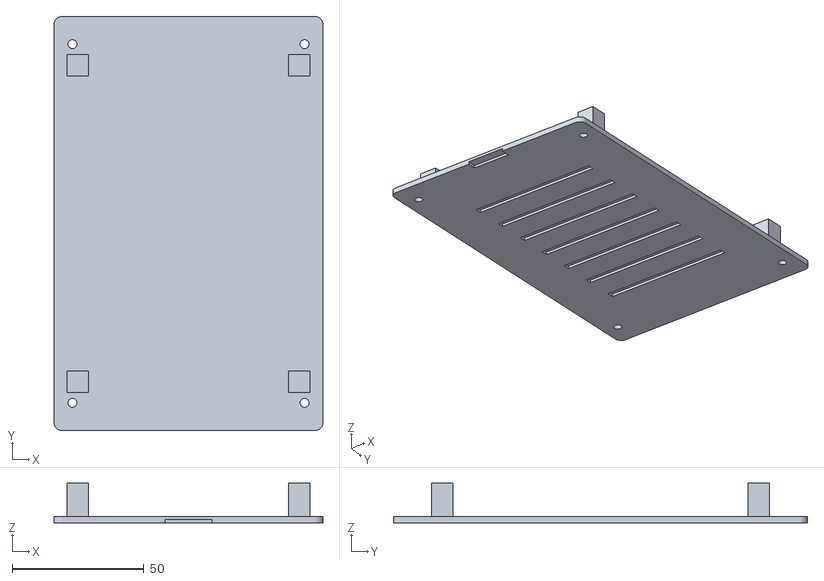
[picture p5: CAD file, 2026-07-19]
mechanical/desktop_enclosure/stl/printable/rear_cover.stl
102.0 x 157.0 x 15.1

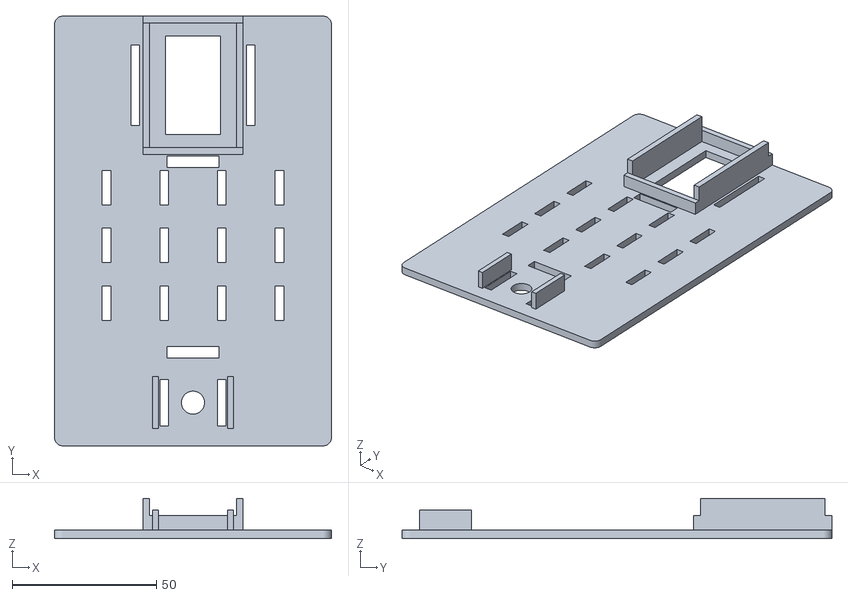
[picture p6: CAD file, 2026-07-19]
mechanical/desktop_enclosure/stl/printable/electronics_tray.stl
96.0 x 149.0 x 14.0

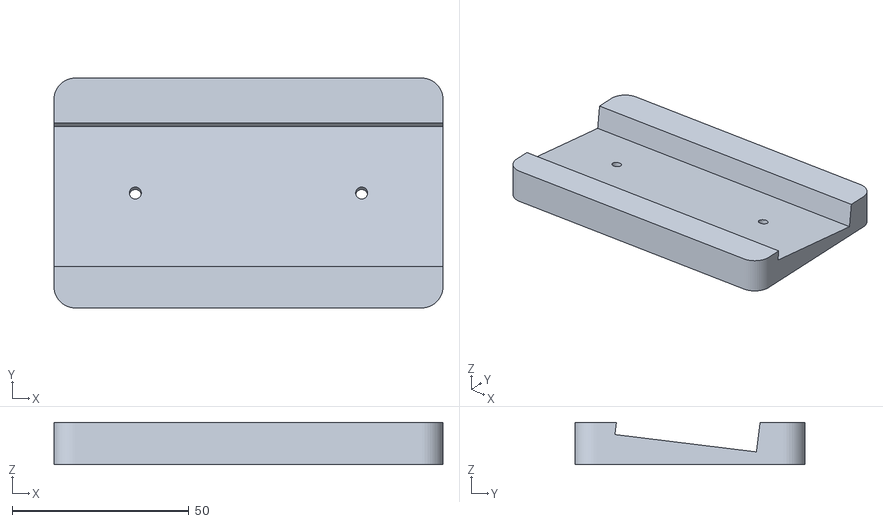
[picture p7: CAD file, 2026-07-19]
mechanical/desktop_enclosure/stl/printable/desktop_base.stl
110.0 x 65.0 x 12.0

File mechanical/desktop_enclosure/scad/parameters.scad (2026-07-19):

$fn = 48;

body_width = 110;
body_height = 165;
body_depth = 40;
wall = 3;
corner_radius = 4;

front_panel_thickness = 2;
panel_clearance = 0.4;
panel_slot_depth = 4;
moving_clearance = 0.3;

camera_aperture_diameter = 12;
camera_board = [27, 42, 19];
camera_clearance = 0.6;
camera_mount_inner_width = 30;
camera_position_z = body_height - 24;

m3_clearance = 3.4;
m3_pilot_diameter = 2.6;
lean_angle = 7;
rear_cover_thickness = 2.4;
rear_opening_margin = 8;
rear_cover_fastener_x = [-44, 44];
rear_cover_fastener_z = [-68, 68];
rear_cover_boss_diameter = 9;

base_width = 110;
base_depth = 65;
base_height = 12;
base_fastener_x = [-32, 32];

tray_width = 96;
tray_height = 149;
tray_thickness = 3;
tray_feature_height = 12;
tray_installed_y = 2;
tray_stop_overlap = 1;
rear_cover_post_gap = 0.5;

service_part_thickness = 3;
controller_rail_length = 90;
epsilon = 0.2;

front_panel_width = body_width - 2 * wall;
front_panel_height = body_height - 2 * wall;

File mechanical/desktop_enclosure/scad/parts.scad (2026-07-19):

module rounded_xy_box(size, radius = 3) {
    linear_extrude(height = size[2])
        offset(r = radius)
            square([size[0] - 2 * radius, size[1] - 2 * radius], center = true);
}

module rounded_plate(width, height, thickness, radius = 2) {
    linear_extrude(height = thickness)
        offset(r = radius)
            square([width - 2 * radius, height - 2 * radius], center = true);
}

module linear_slot(length, diameter, height, axis = "x") {
    hull() {
        for (offset = [-length / 2, length / 2])
            if (axis == "x")
                translate([offset, 0, 0]) cylinder(h = height, d = diameter);
            else
                translate([0, offset, 0]) cylinder(h = height, d = diameter);
    }
}

module shell_frame() {
    difference() {
        rounded_xy_box([body_width, body_depth, body_height], corner_radius);
        translate([0, 0, body_height / 2])
            cube([
                body_width - 2 * wall,
                body_depth + 2 * epsilon,
                body_height - 2 * wall
            ], center = true);
    }
}

module front_panel_rails() {
    rail_x = front_panel_width / 2 - 0.5;
    rail_y = -body_depth / 2 + wall + panel_slot_depth / 2;

    for (x = [-rail_x, rail_x])
        translate([x, rail_y, body_height / 2])
            cube([3, panel_slot_depth, front_panel_height], center = true);
}

module rear_cover_bosses() {
    for (x = rear_cover_fastener_x, z_offset = rear_cover_fastener_z)
        let(
            side = x < 0 ? -1 : 1,
            support_width = body_width / 2 - wall - abs(x) + 2,
            support_x = side * (abs(x) + body_width / 2 - wall) / 2,
            boss_z = body_height / 2 + z_offset
        )
            difference() {
                union() {
                    translate([x, body_depth / 2 - wall, boss_z])
                        rotate([90, 0, 0])
                            cylinder(h = 6, d = rear_cover_boss_diameter, center = true);
                    translate([support_x, body_depth / 2 - wall, boss_z])
                        cube([
                            support_width,
                            6,
                            rear_cover_boss_diameter
                        ], center = true);
                }

                translate([x, body_depth / 2 - wall, boss_z])
                    rotate([90, 0, 0])
                        cylinder(h = 6 + 2 * epsilon, d = m3_pilot_diameter, center = true);
            }
}

module tray_stop_pads() {
    stop_x = tray_width / 2 + 1;
    stop_y = tray_installed_y - tray_thickness - moving_clearance - 2;
    stop_z = tray_height / 2 - 8;

    for (x = [-stop_x, stop_x], z_offset = [-stop_z, stop_z])
        translate([x, stop_y, body_height / 2 + z_offset])
            cube([8, 4, 10], center = true);
}

module base_pilot_bosses() {
    for (x = base_fastener_x)
        translate([x, 0, 0]) cylinder(h = 8, d = 9);
}

module compact_shell_model() {
    difference() {
        union() {
            shell_frame();
            front_panel_rails();
            rear_cover_bosses();
            tray_stop_pads();
            base_pilot_bosses();
        }

        for (x = base_fastener_x)
            translate([x, 0, -epsilon])
                cylinder(h = 8 + 2 * epsilon, d = m3_pilot_diameter);
    }
}

module compact_shell() {
    translate([0, 0, body_width / 2])
        rotate([0, 90, 0]) compact_shell_model();
}

module front_panel() {
    difference() {
        rounded_plate(
            front_panel_width,
            front_panel_height,
            front_panel_thickness,
            3
        );

        translate([0, camera_position_z - body_height / 2, -epsilon])
            cylinder(
                h = front_panel_thickness + 2 * epsilon,
                d = camera_aperture_diameter
            );

        translate([0, -front_panel_height / 2, -epsilon])
            cube([8, 4, front_panel_thickness + 2 * epsilon], center = true);
    }
}

module rear_cover_pressure_posts() {
    post_start_z = rear_cover_thickness - tray_stop_overlap;
    post_height = body_depth / 2 - 2 * rear_cover_thickness
        - tray_installed_y - rear_cover_post_gap + tray_stop_overlap;
    post_z = post_start_z + post_height / 2;

    for (x = [-42, 42], y = [-60, 60])
        translate([x, y, post_z]) cube([8, 8, post_height], center = true);
}

module rear_cover() {
    cover_width = body_width - 2 * rear_opening_margin + 8;
    cover_height = body_height - 2 * rear_opening_margin + 8;

    union() {
        difference() {
            rounded_plate(cover_width, cover_height, rear_cover_thickness, 3);

            for (x = rear_cover_fastener_x, z_offset = rear_cover_fastener_z)
                translate([x, z_offset, -epsilon])
                    cylinder(h = rear_cover_thickness + 2 * epsilon, d = m3_clearance);

            for (y = [-45, -30, -15, 0, 15, 30, 45])
                translate([0, y, -epsilon])
                    cube([60, 3, rear_cover_thickness + 2 * epsilon], center = true);

            translate([0, -cover_height / 2, -epsilon])
                cube([18, 8, rear_cover_thickness + 2 * epsilon], center = true);
        }
        rear_cover_pressure_posts();
    }
}

module desktop_base() {
    slot_cutter_height = 20;
    difference() {
        rounded_xy_box([base_width, base_depth, base_height], 6);

        translate([0, 0, base_height + 4])
            rotate([-lean_angle, 0, 0])
                cube([
                    body_width + moving_clearance,
                    body_depth + moving_clearance,
                    slot_cutter_height
                ], center = true);

        for (x = base_fastener_x)
            translate([x, 0, base_height / 2])
                rotate([-lean_angle, 0, 0])
                    cylinder(
                        h = base_height + 4,
                        d = m3_clearance,
                        center = true
                    );
    }
}

module electronics_tray() {
    camera_inner = [
        camera_mount_inner_width,
        camera_board[1] + 2 * camera_clearance
    ];
    camera_y = tray_height / 2 - camera_board[1] / 2 - 3;
    microphone_y = -tray_height / 2 + 15;
    guide_thickness = 2.4;
    feature_z = tray_thickness - tray_stop_overlap + tray_feature_height / 2;

    difference() {
        union() {
            rounded_plate(tray_width, tray_height, tray_thickness, 3);

            for (x = [
                -camera_inner[0] / 2 - guide_thickness / 2,
                camera_inner[0] / 2 + guide_thickness / 2
            ])
                translate([x, camera_y, feature_z])
                    cube([
                        guide_thickness,
                        camera_inner[1],
                        tray_feature_height
                    ], center = true);

            for (y = [
                camera_y - camera_inner[1] / 2 - guide_thickness / 2,
                camera_y + camera_inner[1] / 2 + guide_thickness / 2
            ])
                translate([0, y, tray_thickness - tray_stop_overlap + 3])
                    cube([
                        camera_inner[0] + 2 * guide_thickness,
                        guide_thickness,
                        6
                    ], center = true);

            for (x = [-13, 13])
                translate([x, microphone_y, tray_thickness - tray_stop_overlap + 4])
                    cube([2, 18, 8], center = true);
        }

        translate([0, camera_y, (tray_thickness + tray_feature_height) / 2])
            cube([
                camera_board[0] - 8,
                camera_board[1] - 8,
                tray_thickness + tray_feature_height + 2 * epsilon
            ], center = true);

        for (x = [-20, 20])
            translate([x, camera_y, tray_thickness / 2])
                cube([3, 28, tray_thickness + 2 * epsilon], center = true);

        for (x = [-30, -10, 10, 30], y = [-25, -5, 15])
            translate([x, y, tray_thickness / 2])
                cube([3, 12, tray_thickness + 2 * epsilon], center = true);

        for (x = [-10, 10])
            translate([x, microphone_y, tray_thickness / 2])
                cube([3, 16, tray_thickness + 2 * epsilon], center = true);

        translate([0, microphone_y, -epsilon])
            cylinder(h = tray_thickness + tray_feature_height + 2 * epsilon, d = 8);

        for (y = [-42, 24])
            translate([0, y, tray_thickness / 2])
                cube([18, 4, tray_thickness + 2 * epsilon], center = true);
    }
}

module installed_front_and_rear() {
    translate([0, -body_depth / 2 + front_panel_thickness, body_height / 2])
        rotate([90, 0, 0]) front_panel();
    translate([0, body_depth / 2 + rear_cover_thickness, body_height / 2])
        rotate([90, 0, 0]) rear_cover();
}

module installed_electronics_tray() {
    color([0.30, 0.35, 0.37])
        translate([0, tray_installed_y, body_height / 2])
            rotate([90, 0, 0]) electronics_tray();
}
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

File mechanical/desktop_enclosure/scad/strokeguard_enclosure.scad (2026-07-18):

part = is_undef(part) ? "assembled" : part;
variant = is_undef(variant) ? "printable" : variant;

include <parameters.scad>
include <parts.scad>

if (part == "compact_shell") compact_shell();
else if (part == "front_panel") front_panel();
else if (part == "electronics_tray") electronics_tray();
else if (part == "rear_cover") rear_cover();
else if (part == "desktop_base") desktop_base();
else if (part == "assembled") assembled_view();
else if (part == "exploded") exploded_view();
else if (part == "display_stl") display_stl_model();
else assert(false, str("Unknown part: ", part));

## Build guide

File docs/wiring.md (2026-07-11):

# StrokeGuard M1b Wiring Plan

本文件是 M1b 硬件接线与配置清单。当前外设未到货，所有 GPIO 均为待确认；固件默认不启用任何新增驱动，继续发送 synthetic frame，避免把未验证接线写死进代码。

## Scope

- 主控：ESP32-S3-WROOM-1 N16R8。
- 不新增镜端硬件，沿用原 BOM：GC2145、INMP441、MAX98357A、ST7789、RGB LED、蜂鸣器、3 个按键。
- 原始音视频只在本地处理，云端只接收数值评分与用户档案。
- Arm 因镜子视野限制不单独测量；如后续需要补 Arm 项，应通过可穿戴或外部设备另行设计。

## Kconfig Rules

在 `idf.py menuconfig` 中进入 `StrokeGuard M1a/M1b Config -> M1b hardware scaffold`：

- `STROKEGUARD_HW_CAMERA_ENABLE`：GC2145 到货并接线确认后再启用。
- `STROKEGUARD_HW_AUDIO_IN_ENABLE`：INMP441 到货并接线确认后再启用。
- `STROKEGUARD_HW_DISPLAY_ENABLE`：ST7789 到货并接线确认后再启用。
- `STROKEGUARD_HW_AUDIO_OUT_ENABLE`：MAX98357A 到货并接线确认后再启用。
- `STROKEGUARD_HW_ALERT_ENABLE`：RGB LED、蜂鸣器、按键接线确认后再启用。
- 所有引脚默认 `-1`，表示待确认/未分配。

## Wiring Checklist

| Module | Signals | Current Status |
| --- | --- | --- |
| GC2145 | PWDN, RESET, XCLK, SIOD, SIOC, PCLK, VSYNC, HREF, D0-D7 | 待确认 |
| INMP441 | BCLK, WS/LRCLK, SD/DIN | 待确认 |
| ST7789 | MOSI, SCLK, CS, DC, RST, BL | 待确认 |
| MAX98357A | BCLK, LRC, DIN | 待确认 |
| RGB LED | DATA | 待确认 |
| Buzzer | GPIO | 待确认 |
| Buttons | BTN1, BTN2, BTN3 | 待确认 |

## Bring-Up Order

1. 保持所有 `STROKEGUARD_HW_*_ENABLE=n`，确认 USB-CDC synthetic frame 仍可收帧。
2. 到货后先接 INMP441，验证 16 kHz I2S 采样与 MFCC 维度。
3. 再接 GC2145，验证 JPEG 输出能进入 `type="frame"` 的 `jpeg_b64` 字段。
4. 最后接 ST7789、MAX98357A、RGB LED、蜂鸣器和按键，用于显示/播报/报警交互。

## Safety Note

本项目是风险提示/就医提醒工具，不是诊断设备。危险等级只提示尽快就医或拨打 120，不给出诊断结论。

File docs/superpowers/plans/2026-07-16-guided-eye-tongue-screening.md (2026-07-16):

# Guided Eye And Tongue Screening Implementation Plan

> **For agentic workers:** REQUIRED SUB-SKILL: Use superpowers:subagent-driven-development (recommended) or superpowers:executing-plans to implement this plan task-by-task. Steps use checkbox (`- [ ]`) syntax for tracking.

**Goal:** Add a web-started, device-local guided screening that publishes real F/E/T values from the GC2145 camera board through N16R8 and VPS without uploading images.

**Architecture:** Shared fixed-size I2C messages define control, stage, E, and T registers. The camera coprocessor owns the guided state machine and fixed-storage RGB ROI algorithms; N16R8 forwards authenticated MQTT control, polls results, fuses locally, and uploads numeric state. FastAPI publishes control and exposes state to the existing authenticated demo UI.

**Tech Stack:** ESP-IDF 5.5.3, ESP-WHO/ESP-DL, C/C++, Unity, I2C, ESP-MQTT, FastAPI, Pydantic, Paho MQTT, vanilla HTML/CSS/JavaScript, pytest.

## Global Constraints

- Raw images, ROIs, landmarks, and personal baselines remain local and never enter MQTT, InfluxDB, VPS, or the LLM.
- Missing or quality-rejected E/T values remain invalid; no layer substitutes `100`.
- T is auxiliary only and never triggers a single-item danger veto.
- Existing F register `0x02` and existing advice downlink remain compatible.
- Stage durations of 3/2/2/2/3 seconds and all image thresholds are engineering defaults pending real-device measurement.
- Every task ends with tests, a commit, and a push to `codex/preliminary-demo`.

---

### Task 1: Shared I2C Screening Protocol

**Files:**
- Modify: `firmware_common/camera_scores_protocol.h`
- Modify: `firmware_common/camera_scores_protocol.c`
- Modify: `firmware_camera/test_apps/face_geometry/main/test_face_geometry.cpp`
- Modify: `host_pc/tests/test_camera_coprocessor_firmware.py`

**Interfaces:**
- Produces: registers `SG_CAMERA_EYE_REGISTER=0x03`, `SG_CAMERA_TONGUE_REGISTER=0x04`, `SG_CAMERA_CONTROL_REGISTER=0x10`, `SG_CAMERA_STAGE_REGISTER=0x11`.
- Produces: four-byte `sg_camera_modal_response_t`, control enum, and stage enum shared by both boards.

- [ ] Add failing protocol tests asserting all register values, `sizeof(sg_camera_modal_response_t) == 4`, signed offset round trips, and rejection of invalid status/score/stage bytes.
- [ ] Run `python -m pytest host_pc/tests/test_camera_coprocessor_firmware.py -q` and build the Unity app; verify failures are caused by missing protocol symbols.
- [ ] Add the exact shared types and helpers:

```c
typedef struct __attribute__((packed)) {
    uint8_t valid;
    uint8_t score;
    int8_t signed_value;
    uint8_t quality;
} sg_camera_modal_response_t;

typedef enum { SG_SCREENING_CANCEL = 0, SG_SCREENING_START = 1 } sg_screening_control_t;
typedef enum {
    SG_STAGE_IDLE = 0, SG_STAGE_FACE, SG_STAGE_EYE_CENTER, SG_STAGE_EYE_LEFT,
    SG_STAGE_EYE_RIGHT, SG_STAGE_TONGUE, SG_STAGE_DONE, SG_STAGE_ERROR
} sg_screening_stage_t;
```

- [ ] Implement strict encode/parse functions using byte assignment, not struct pointer casting.
- [ ] Re-run focused pytest and Unity tests; expect all protocol cases to pass.
- [ ] Commit and push as `feat(protocol): add guided screening registers`.

### Task 2: Pure E Pupil-Tracking Kernel

**Files:**
- Create: `firmware_camera/main/eye_tracking.h`
- Create: `firmware_camera/main/eye_tracking.cpp`
- Create: `firmware_camera/test_apps/eye_tongue/CMakeLists.txt`
- Create: `firmware_camera/test_apps/eye_tongue/main/CMakeLists.txt`
- Create: `firmware_camera/test_apps/eye_tongue/main/test_eye_tongue.cpp`
- Modify: `host_pc/tests/test_camera_coprocessor_firmware.py`

**Interfaces:**
- Consumes: RGB888 image, width/height, two eye centers, inter-eye distance, and eye-line angle.
- Produces: `bool sg_eye_measure(const sg_eye_input_t *, sg_eye_measurement_t *)` with normalized left/right horizontal centroids and quality `0..100`.

- [ ] Write failing Unity tests using small synthetic RGB images for centered pupils, same-direction displacement, opposite-direction displacement, low contrast, implausible dark area, and ROI clipping.
- [ ] Build the test app and verify RED because `sg_eye_measure` is absent.
- [ ] Implement bounded ROI extraction, integer intensity, histogram-derived dark threshold, dark-area gate, weighted centroid, and contrast-derived quality without heap allocation.
- [ ] Add `sg_eye_score_sequence(center, left, right, out)` and failing tests requiring common-direction travel, minimum travel, binocular agreement, and `0..100` bounds.
- [ ] Implement the minimum sequence scorer and run all eye tests to GREEN.
- [ ] Run focused host structural tests to ensure eye code contains no network, file, or allocation API.
- [ ] Commit and push as `feat(camera): add local eye movement scoring`.

### Task 3: Pure Auxiliary T Segmentation Kernel

**Files:**
- Create: `firmware_camera/main/tongue_deviation.h`
- Create: `firmware_camera/main/tongue_deviation.cpp`
- Modify: `firmware_camera/test_apps/eye_tongue/main/CMakeLists.txt`
- Modify: `firmware_camera/test_apps/eye_tongue/main/test_eye_tongue.cpp`
- Modify: `host_pc/tests/test_camera_coprocessor_firmware.py`

**Interfaces:**
- Consumes: RGB888 lower-face ROI and roll-corrected facial midline.
- Produces: `bool sg_tongue_measure(const sg_tongue_input_t *, sg_tongue_measurement_t *)` with signed offset percentage, auxiliary score, and quality.

- [ ] Add failing synthetic-image tests for centered tongue, left/right offset, absent red component, tiny component, border-touching component, and low saturation.
- [ ] Verify RED because `sg_tongue_measure` is absent.
- [ ] Implement red-dominance/saturation selection, fixed-size scanline connected-component labeling, geometry gates, centroid, signed offset, and quality without heap allocation.
- [ ] Implement a continuous configurable score mapping where zero offset is highest and large absolute offset is lower; clamp every output to its wire range.
- [ ] Run the eye/tongue Unity app and focused privacy/structure pytest to GREEN.
- [ ] Commit and push as `feat(camera): add auxiliary tongue deviation scoring`.

### Task 4: Camera Guided State Machine And I2C Serving

**Files:**
- Create: `firmware_camera/main/screening_session.h`
- Create: `firmware_camera/main/screening_session.c`
- Modify: `firmware_camera/main/camera_capture_adapter.h`
- Modify: `firmware_camera/main/camera_capture_adapter.cpp`
- Modify: `firmware_camera/main/camera_score_target.c`
- Modify: `firmware_camera/main/app_main.c`
- Modify: `firmware_camera/main/CMakeLists.txt`
- Modify: `firmware_camera/test_apps/eye_tongue/main/test_eye_tongue.cpp`

**Interfaces:**
- Consumes: start/cancel writes on `0x10`, monotonic time, face geometry, eye measurements, and tongue measurements.
- Produces: stage on `0x11`, E on `0x03`, T on `0x04`, and unchanged F on `0x02`.

- [ ] Write failing state tests for exact stage order, three accepted samples, timeout to error, cancel to idle, duplicate start restart, and invalid values before completion.
- [ ] Verify RED, then implement `sg_screening_session_start`, `cancel`, `update`, `stage`, `eye_result`, and `tongue_result` with fixed RAM state.
- [ ] Integrate the state machine into the existing RGB888 frame path; derive eye and lower-face ROIs only when their stage is active.
- [ ] Extend the I2C receive callback so a two-byte `[0x10, command]` write changes state, while one-byte writes remain register selection.
- [ ] Serve all new read registers through the existing event queue and keep ISR callbacks allocation-free.
- [ ] Build production camera firmware and the Unity app; run focused pytest.
- [ ] Flash COM4 and verify serial stage transitions with images obscured first, then a guided valid run.
- [ ] Commit and push as `feat(camera): run guided F E T screening`.

### Task 5: N16R8 Control, Polling, Fusion, And Numeric Uplink

**Files:**
- Modify: `firmware_esp32/main/camera_coprocessor.h`
- Modify: `firmware_esp32/main/camera_coprocessor.c`
- Modify: `firmware_esp32/main/sg_mqtt.h`
- Modify: `firmware_esp32/main/sg_mqtt.c`
- Modify: `firmware_esp32/main/cloud_contract.h`
- Modify: `firmware_esp32/main/cloud_contract.c`
- Modify: `firmware_esp32/main/app_main.c`
- Modify: `host_pc/tests/test_e1_standalone_firmware.py`
- Modify: `host_pc/tests/test_e1_cloud_contract.py`

**Interfaces:**
- Consumes: MQTT `screening_control` downlink and camera registers `0x03/0x04/0x11`.
- Produces: score-bus E/T values, immediate uplink on stage changes, and uplink field `screening_stage`.

- [ ] Add failing tests for strict start/cancel JSON parsing, rejection of unknown actions, I2C command writes, E/T validity propagation, stage serialization, and no media fields.
- [ ] Verify focused tests fail for missing APIs.
- [ ] Generalize the downlink callback to a tagged event containing either advice or screening control; keep existing advice age validation unchanged.
- [ ] Add `sg_camera_coprocessor_control()` and extend polling to parse stage/E/T, writing only valid scores into `sg_score_bus`.
- [ ] Extend numeric uplink JSON with a bounded `screening_stage`; trigger publish when the stage changes while retaining periodic publication.
- [ ] Build N16R8 firmware, run focused host tests, flash COM3, and verify I2C stage/E/T logs.
- [ ] Commit and push as `feat(edge): bridge guided screening to MQTT`.

### Task 6: Authenticated VPS Start Endpoint And State Schema

**Files:**
- Modify: `cloud/backend/app/schemas.py`
- Modify: `cloud/backend/app/mqtt_bridge.py`
- Modify: `cloud/backend/app/demo_api.py`
- Modify: `host_pc/tests/test_demo_api.py`
- Modify: `host_pc/tests/test_e1_cloud_contract.py`

**Interfaces:**
- Consumes: authenticated, device-bound `POST /demo/api/screening` with `{"action":"start"}` or `{"action":"cancel"}`.
- Produces: QoS 1 MQTT control publish, `screening_stage` in `GET /demo/api/device`, and authenticated `/demo/api/ws` state pushes.

- [ ] Write failing API tests for unauthenticated, unbound, offline, invalid-action, start, and cancel requests; assert the topic matches the bound device and payload contains no user-supplied device ID.
- [ ] Add strict Pydantic request/stage fields and a bridge method `publish_screening_control(device_id, action)`.
- [ ] Implement the endpoint using the signed session's bound device, online check, fixed action allowlist, and MQTT connectivity check.
- [ ] Include bounded stage in the monitor response while preserving old-device compatibility when the field is absent.
- [ ] Add an authenticated WebSocket endpoint that validates the signed cookie and bound device, sends a snapshot whenever the bridge cache generation changes, sends no raw MQTT payload, and closes cleanly on logout/session expiry.
- [ ] Add WebSocket tests for missing/invalid session, unbound session, first snapshot, changed-generation push, and disconnect cleanup.
- [ ] Run demo API, cloud contract, auth, and MQTT bridge tests.
- [ ] Commit and push as `feat(cloud): add authenticated screening control`.

### Task 7: Preliminary Demo Guided UI

**Files:**
- Modify: `cloud/backend/app/static/demo/index.html`
- Modify: `cloud/backend/app/static/demo/app.css`
- Modify: `cloud/backend/app/static/demo/app.js`
- Modify: `host_pc/tests/test_demo_web.py`

**Interfaces:**
- Consumes: `/demo/api/screening`, `/demo/api/ws`, and `/demo/api/device` stage/F/E/T/advice fields.
- Produces: one Start/Cancel control, prominent current instruction, compact progress, measured scores, retry/error state, and advice.

- [ ] Write failing DOM/source tests for authenticated start/cancel calls, WebSocket connection/reconnect, five-second polling fallback, disabled controls while offline, stage-to-Chinese-instruction mapping, missing-value display, and no simulation path.
- [ ] Add a compact screening command bar and stage progress without nesting cards or changing the existing login/device-connect flow.
- [ ] Implement start/cancel requests and WebSocket state updates; on socket close or error automatically poll `/demo/api/device` every five seconds until WebSocket reconnects.
- [ ] Map stages to concise prompts: face front, center gaze, look left, look right, extend tongue, complete, retry.
- [ ] Keep F/E/T unavailable until valid server data arrives and label T as auxiliary.
- [ ] Run demo web/API tests and inspect desktop/mobile layouts in a browser screenshot with no overlap or clipped text.
- [ ] Commit and push as `feat(demo): add guided screening controls`.

### Task 8: End-To-End Hardware And VPS Acceptance

**Files:**
- Modify: `firmware_camera/README.md`
- Modify: `docs/camera-nmo432-bringup.md`
- Modify: `README.md`

**Interfaces:**
- Produces: reproducible flashing, guided demonstration, measured observations, and known limitations.

- [ ] Deploy the updated cloud backend to `/opt/strokeguard/cloud`, restart native services, and verify health locally and through `http://106.75.229.61:8000/health`.
- [ ] Flash COM4 camera and COM3 N16R8 production firmware using `C:\Espressif\tools\Microsoft.v5.5.3.PowerShell_profile.ps1`.
- [ ] Start a web screening and capture evidence at every boundary: API accepted, downlink received, camera stage advanced, E/T registers valid, numeric uplink cached, and advice returned.
- [ ] Repeat with camera obscured and verify retry/unavailable instead of `100`.
- [ ] Record measured device timing and observed limitations without accuracy claims.
- [ ] Run the complete host pytest suite, build both firmware projects, and run `git diff --check`.
- [ ] Remove generated test builds, pytest caches, and logs; update the three documents with exact commands and safety language.
- [ ] Commit and push as `docs(demo): document guided screening flow`.

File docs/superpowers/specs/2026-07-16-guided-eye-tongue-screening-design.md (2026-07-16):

# Guided Eye And Tongue Screening Design

## Goal

Add a guided preliminary-contest screening flow that computes eye-movement (E)
and auxiliary tongue-deviation (T) scores locally on the GC2145 camera board.
The web demo starts the flow and displays progress, numeric results, and cloud
advice. Raw images, image regions, and landmarks never leave the local device.

This feature provides risk prompts only. It is not a diagnosis. Tongue
observation is an auxiliary reference and never acts as a single-item veto.

## User Flow

The user starts a screening from the authenticated VPS demo page. The VPS sends
a small MQTT control message to the N16R8. The N16R8 writes a start command to
the camera board over I2C. The camera board advances through these stages:

1. Neutral frontal face and F baseline: approximately 3 seconds.
2. E center gaze: approximately 2 seconds.
3. E left gaze: approximately 2 seconds.
4. E right gaze: approximately 2 seconds.
5. T mouth open with tongue extended: approximately 3 seconds.
6. Complete or retry.

The total target duration is about 12 seconds. These durations are preliminary
engineering defaults and must be measured on the real device. Each stage needs
three consecutive quality-accepted samples. A timeout or invalid image produces
a retry state, not a healthy score.

## Architecture

### Camera coprocessor

The camera board retains ESP-WHO five-point face detection and the volatile F
baseline. It uses the RGB888 frame already produced for face detection to run
two bounded, fixed-storage image algorithms:

- Eye ROI pupil-centroid tracking for E.
- Lower-face color segmentation and connected-component geometry for T.

No additional model or training weight is required. The camera board owns the
screening state machine and exposes progress and numeric results through I2C.

### N16R8 main controller

The N16R8 receives a screening start/cancel command through its existing MQTT
connection, forwards the command to the camera board over I2C, polls stage and
F/E/T values, performs the existing local fusion, and uploads numeric values and
stage only. Offline local fusion remains available. Missing modalities remain
missing and are never replaced with 100.

### VPS web application

The authenticated demo page provides one Start Screening command, displays the
current guided stage, and shows resulting F/E/T values. Existing WebSocket
delivery with five-second polling fallback remains in place. The cloud and LLM
receive only numeric scores, stage, and the permitted user profile.

## I2C Contract

Existing register `0x02` remains unchanged:

| Register | Direction | Four-byte payload |
|---|---|---|
| `0x02` | Camera to N16R8 | F: `[valid, score, signed_angle, quality]` |
| `0x03` | Camera to N16R8 | E: `[valid, score, gaze_diff, quality]` |
| `0x04` | Camera to N16R8 | T: `[valid, score, signed_offset, quality]` |
| `0x10` | N16R8 to camera | Control: `start` or `cancel` |
| `0x11` | Camera to N16R8 | Stage: `idle/F/E-center/E-left/E-right/T/done/error` |

All scores and quality values use `0..100`. Signed offset is a bounded signed
percentage of face width. `valid=0` means the remaining score fields must not be
used. Exact command and stage byte constants are defined once in the shared
camera protocol header and consumed by both firmware projects.

## MQTT Extension

The downlink accepts this additional message without changing the existing LLM
advice payload:

```json
{"type":"screening_control","action":"start"}
```

Cancel uses `"action":"cancel"`. Uplink messages retain the existing numeric
scores and add a bounded screening stage field. No image, audio, ROI, landmark,
or personal F baseline data is permitted in either direction.

## E Algorithm

The five ESP-WHO landmarks do not include iris landmarks. E therefore uses
local image evidence rather than treating eye centers as gaze:

1. Derive left and right eye ROIs from detected eye centers and inter-eye
   distance, corrected for eye-line roll.
2. Convert each ROI to intensity and apply an adaptive dark-pixel threshold.
3. Reject ROIs with insufficient contrast, implausible dark area, closure, or
   strong reflection contamination.
4. Compute each pupil candidate's horizontal centroid relative to its eye ROI.
5. Establish the center stage baseline.
6. During left and right stages, require both pupils to move in the expected
   common direction with sufficient travel.
7. Score from binocular movement disagreement, travel adequacy, and temporal
   stability. Publish only after three accepted samples per stage.

This is a guided ocular-movement risk prompt inspired by BE-FAST Eyes. It does
not measure visual-field loss or diagnose ocular palsy. Glasses, eyelid closure,
head rotation, and poor illumination can make the result unavailable.

## T Algorithm

T is evaluated only during the explicit tongue stage:

1. Correct the face coordinate system using eye-line roll.
2. Derive a lower-face ROI from the nose, mouth corners, and face box.
3. Select pixels using configurable red-dominance and saturation thresholds.
4. Find the largest plausible connected component and reject insufficient area,
   border contact, implausible aspect ratio, or unstable masks.
5. Estimate the tongue centerline and tip-side centroid relative to the
   roll-corrected facial midline.
6. Convert the signed offset ratio to an auxiliary `0..100` score and publish
   only after three accepted samples.

Lipstick, warm lighting, skin tone, mouth interior, and partial tongue exposure
can affect segmentation. Thresholds are engineering defaults pending real-device
calibration. T never triggers danger by itself.

## State And Error Handling

- Start clears prior E/T samples and begins a new RAM-only session.
- Cancel immediately returns to idle and invalidates incomplete E/T results.
- Loss of a valid face pauses the current stage briefly; stage timeout produces
  error/retry and invalid scores.
- A new start command recovers from complete or error without rebooting.
- I2C or MQTT failure does not invent results. N16R8 retains local operation and
  reports unavailable cloud connectivity separately.
- Only one screening session runs at a time. Duplicate start commands restart
  the guided sequence deterministically.

## Testing And Acceptance

### Automated tests

- Pure image-kernel tests use synthetic RGB fixtures for centered, conjugate,
  and discordant pupil positions.
- Tongue tests cover centered, left/right offset, insufficient area, and absent
  tongue masks.
- State-machine tests cover stage order, three-sample gating, timeout, cancel,
  duplicate start, and invalid-result behavior.
- Shared protocol tests verify all register payload sizes and constants.
- Host tests verify MQTT and web payloads contain numeric data only.

### Hardware acceptance

- COM4 completes the guided sequence and publishes measured F/E/T values.
- COM3 reads all camera registers and uploads the same numeric values through
  MQTT.
- The VPS page starts a session, shows each stage in real time, displays retry
  on invalid capture, and shows the resulting Doubao advice.
- Disconnecting or obscuring the camera produces unavailable/retry, never an
  automatic score of 100.

No sensitivity, specificity, latency, or medical accuracy claim is accepted
until measured with an explicitly documented evaluation set.

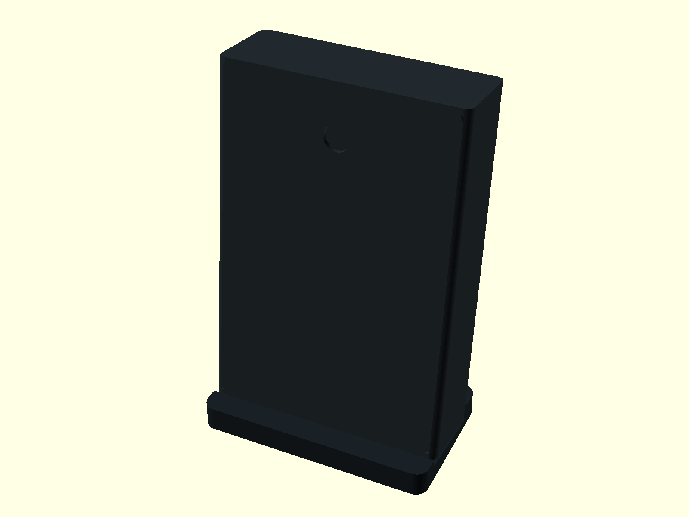
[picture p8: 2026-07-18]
mechanical/desktop_enclosure/renders/assembled.png

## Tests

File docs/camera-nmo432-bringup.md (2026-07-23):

# Camera Coprocessor and NMO432 Bring-up

## Hardware

- Main controller: ESP32-S3-WROOM-1 N16R8.
- Camera: Hiwonder ESP32-S3-Cam with its expansion board.
- Microphone: NMO432 digital I2S module, powered only from 3.3 V.
- ST7789, MAX98357A, RGB, buzzer, and buttons are not used.

Power off before changing wiring. All modules must share GND. Verify the
camera expansion-board I2C connector order and 3.3 V logic level before power.

| Signal | Peripheral | N16R8 |
| --- | --- | --- |
| Camera SDA | camera GPIO47 | GPIO8 |
| Camera SCL | camera GPIO48 | GPIO9 |
| Camera ground | GND | GND |
| NMO432 SCK | SCK | GPIO17 |
| NMO432 WS | WS | GPIO18 |
| NMO432 SD | SD | GPIO16 |
| NMO432 supply | VDD | 3.3 V |
| NMO432 ground | GND | GND |

Tie NMO432 `L/R` to GND for the configured left slot, or to 3.3 V for the
right slot. The deployment YAML channel must match this connection.

## Build and flash

Open `C:\Users\Administrator\Desktop\IDF_v5.5.3_Powershell.lnk`.

```powershell
cd F:\iot_design\firmware_esp32
idf.py build
idf.py -p COM3 flash monitor

Get-CimInstance Win32_SerialPort | Select-Object DeviceID,Name
cd F:\iot_design\firmware_camera
idf.py set-target esp32s3
idf.py build
idf.py -p COM4 flash monitor
```

The camera expansion board must use its own USB serial port, not COM3. Do not
run `erase-flash` unless intentionally clearing all local configuration. Keep
the inter-board 5 V jumper disconnected; both boards are powered by USB and
share only GND plus I2C.

## Local camera preview

The optional USB preview is only for local debugging. Close `idf.py monitor`
and every other COM4 serial tool, then run from `F:\iot_design`:

```powershell
host_pc\.venv\Scripts\python.exe host_pc\tools\camera_usb_preview.py --port COM4
```

The camera preview uses `921600 8N1`. It requests one JPEG at a time and does
not record or upload frames. The N16R8 connection is separate: I2C remains active
on GPIO8/GPIO9 while the PC preview window is connected. The displayed box is
face-presence geometry only. The production F score is a separate numeric
result computed locally from ESP-WHO five-point landmarks.

## Expected behavior

- Camera I2C address is `0x52`; bbox register `0x01` remains for debugging.
  N16R8 polls F `0x02`, E `0x03`, T `0x04`, and stage `0x11`. It controls a
  session by writing `0x10,1` (start) or `0x10,0` (cancel).
- Camera firmware runs local GC2145 capture plus ESP-WHO human face detection
  and retains the normalized bbox for USB preview.
- ESP-WHO's two eyes, nose, and two mouth corners feed quality gating,
  eye-line roll correction, asymmetry scoring, and a personal baseline. A
  valid frontal face produces `F score`, signed mouth angle, and quality on
  register `0x02`; rejected frames do not create a healthy score.
- The five-point F result is an initial risk feature, not a diagnosis or a
  replacement for evaluated 68-point analysis. Its thresholds and accuracy
  remain pending measured calibration.
- A guided session asks for frontal face, center gaze, left gaze, right gaze,
  and tongue extension. E uses local pupil ROIs; T uses a local lower-face
  color component. Invalid regions remain unavailable rather than healthy.
- E is an ocular-movement risk prompt and does not test visual fields. T is
  auxiliary only and never causes a single-item danger result. If the tongue
  action is not completed, T remains unavailable and is excluded from fusion.
  A lip-colored region that does not extend below the mouth line is rejected;
  it cannot produce a centered T=100 result.
- Starting a new guided run does not blank the last valid E/T/S values. New
  valid results replace them; an incomplete tongue action clears T and excludes
  it from fusion. Speech remains available for up to five minutes and uses a
  preliminary, unvalidated calibration that must be measured in M6.
- A same-direction or otherwise invalid guided eye sequence is unavailable,
  not a zero risk score. The session continues to T and may use continuous E.
- NMO432 logs aggregate RMS, peak, and valid-block counts every five seconds.
  These are electrical diagnostics, not a speech-risk score.
- S remains unavailable without an evaluated versioned model.
- Missing modalities keep fusion at `insufficient`; they never become zero or
  fabricated normal scores.

## Acceptance

1. Run both boards for 30 minutes without resets.
2. Disconnect camera I2C; CSI, Wi-Fi, MQTT, and NMO432 must continue.
3. Reconnect I2C; camera communication must recover without reboot.
4. Speak near NMO432 and verify RMS/peak change; silence must not create S.
5. Confirm MQTT and InfluxDB contain no JPEG, PCM, MFCC, or raw media.
6. Hold a well-lit frontal face steady for five valid frames and verify COM3
   logs `camera F score=... angle=... quality=...`.
7. Start a guided session from the authenticated VPS page and follow the F/E/T
   prompts. Confirm COM3 reports stage changes and E/T only after completion.
8. Obscure the camera during another session and confirm error/retry with
   unavailable F/E/T rather than 0 or 100.

## Verified NMO432 bring-up

On 2026-07-17, the N16R8 on COM3 reported `valid=250/250` audio blocks with
non-constant RMS and peak values (`rms=8.7..17.9`, `peak=25..41`) using GPIO17,
GPIO18, GPIO16, and the left slot (`L/R` tied to GND). This confirms I2S bus
activity and sample capture for the installed module. The observed amplitude
is only a wiring/driver bring-up result; microphone gain, acoustic response,
and S-model thresholds remain to be calibrated with recorded local test data.

This product provides risk prompts and medical-attention reminders, not a
diagnosis. Arm weakness is not independently measured by the mirror.

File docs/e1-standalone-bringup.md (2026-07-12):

# E1 Standalone Mirror Bring-up

## Scope and safety boundary

E1 runs deterministic fusion, local risk prompts, and MQTT directly on the
ESP32-S3. A PC is optional for flashing and observation; disconnecting it must
not stop the mirror's local fusion loop. The device is a risk prompt and
care-seeking reminder, not a diagnostic device.

Only numeric scores, fusion level, limited profile fields, timestamps, and
advice text may leave the device. JPEG, audio, MFCC, landmarks, ROIs, and any
other reconstructable biometric data must never be published to MQTT.

## Required configuration

1. Use a WPA2-capable **2.4 GHz** Wi-Fi network. ESP32-S3 cannot join a 5 GHz
   SSID. A 20 MHz channel is preferred for CSI repeatability.
2. In `idf.py menuconfig`, set `StrokeGuard M1a/M1b Config` values for Wi-Fi,
   device ID, broker URI, device MQTT username/password, and the limited
   profile defaults. Do not commit `firmware_esp32/sdkconfig`.
3. For the controlled-development deployment use `mqtt://<public-ip>:1883`.
   TLS, device-specific ACLs, and port 8883 are E6 production requirements.
4. Keep `STROKEGUARD_LEGACY_USB_STREAM` disabled. USB is diagnostic telemetry,
   not a runtime score input.
5. Set a random `STROKEGUARD_MANAGER_TOKEN` only in the ignored local
   `sdkconfig`. The PC stores the matching value in the operating-system
   credential store, never in YAML.

Before flashing a changed factory configuration, clear only the NVS partition
(`0x9000`, length `0x6000`) or provision a valid updated NVS blob. E1 validates
the stored configuration with a schema version and CRC, so old valid NVS data
takes precedence over newly compiled defaults.

## Build and flash

Target board: ESP32-S3-WROOM-1 N16R8 on `COM3`.

```powershell
cd firmware_esp32
idf.py build
idf.py -p COM3 flash monitor
```

The local Espressif installation may require its v5.5.3 Python virtual
environment instead of a system Python. Verify the final build reports an app
binary within the 2 MB factory partition before flashing.

## Acceptance checklist

### Offline path

1. Boot the board and confirm `boot fw=e1-0.5.0`.
2. Confirm periodic `fusion` telemetry continues with no PC score input.
3. With CSI as the only available modality, expect `level=insufficient` and
   `avail weight sum 0.08 < 0.50`. This is the honest E1 result, not a normal
   health result.
4. Disconnect the PC or block the WAN. Fusion and local alert logic must
   continue; failed MQTT connection attempts must not block the loop.
5. The Unity target tests verify that a face veto produces `danger` and cloud
   advice cannot lower a local `danger` level.

### Cloud path

1. Confirm the mirror receives a 2.4 GHz IP address, then wait for
   `mqtt connected`.
2. Confirm an uplink on `strokeguard/<device_id>/uplink` contains only the
   versioned numeric contract: `schema_version`, `seq`, `scores`, `level`,
   `profile`, `reasons`, `veto_by`, `device_id`, and `ts`.
3. Confirm FastAPI `/health` reports `status=ok`, `mqtt=true`, and
   `influx=true`.
4. Confirm `/devices/<device_id>/latest` contains a recent numeric uplink and
   a downlink with `schema_version=1`, a bounded `advice_text`, timestamp, and
   source.
5. Confirm an LLM failure sends the fixed fallback safety text rather than a
   provider error. Cloud advice cannot override the device's authoritative
   fusion level.

### LAN management path

1. Confirm serial output includes `GOT_IP address=<S3_LAN_IP>` and
   `manager API started`.
2. A GET without Bearer authorization must return `401`; an authenticated GET
   must return `200` without MQTT or management credentials.
3. PUT the current profile with the returned revision. It must return `200`
   and increment revision exactly once. Replaying the old request must return
   `409`.
4. Reboot the S3 and GET again. The accepted profile and revision must persist.
5. During all requests, confirm CSI/fusion telemetry continues. Closing the PC
   must not affect local fusion or alerts.

## Current evidence (2026-07-12)

- Production firmware built successfully at `0xee600`, with 53% free in the
  2 MB app partition. Values are build output, not estimated runtime usage.
- COM3 was identified as an ESP32-S3 N16R8 with 8 MB PSRAM and 16 MB flash.
- The production image was written with verified hashes after clearing NVS.
- Ten on-device Unity cases passed, covering local danger authority, fusion
  vetoes, NVS migration, revision updates, strict JSON parsing, Token matching,
  and credential-free responses.
- LAN black-box acceptance returned `401/200/200/409`; revision incremented,
  no credential fields appeared, and fusion continued during requests.
- The PC client/UI pulled and pushed a real profile through a separate QThread;
  full host regression passed 194 tests and visual QA covered 1220x820 and
  1024x720.
- The S3 joined 2.4 GHz Wi-Fi and produced local CSI/fusion continuously.
- Cloud acceptance is not complete: MQTT port 1883 accepted TCP but did not
  return CONNACK, while public FastAPI port 8000 timed out. Do not claim the
  VPS/LLM path as passing until remote services are repaired and retested.

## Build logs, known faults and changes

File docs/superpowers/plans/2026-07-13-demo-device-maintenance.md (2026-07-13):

# StrokeGuard Demo Device Maintenance Implementation Plan

> **For agentic workers:** REQUIRED SUB-SKILL: Use superpowers:subagent-driven-development (recommended) or superpowers:executing-plans to implement this plan task-by-task. Steps use checkbox (`- [ ]`) syntax for tracking.

**Goal:** Replace the current all-purpose desktop demo with a focused real-device VPS monitor plus an isolated ESP-IDF/YAML/serial maintenance workspace.

**Architecture:** A small Python service layer owns cloud sessions, deployment configuration, and controlled ESP-IDF subprocesses. A new PyQt5 shell presents a quiet read-only demo dashboard by default and opens maintenance tools in a separate page; neither layer imports the legacy perception/simulation pipeline. The EXE uses the installed ESP-IDF v5.5.3 and never bundles credentials or simulated data.

**Tech Stack:** Python 3.11+, PyQt5, httpx, PyYAML, pyserial, ESP-IDF v5.5.3, pytest, pytest-qt, PyInstaller.

## Global Constraints

- Default cloud URL is configurable and the default device is `sg-0001`.
- Only real VPS telemetry and completed LLM advice may appear; no simulated fallback exists.
- User-visible failure labels are exactly `云端不可达`, `登录失效`, `设备离线`, and `数据未接入`; implementations must not collapse them into one generic error.
- Raw audio/video, MFCC, landmarks, ROI, credentials, and unrestricted logs never enter cloud/UI release output.
- Target firmware is ESP32-S3-WROOM-1 N16R8 with ESP-IDF v5.5.3.
- GC2145 and NMO432 stay disabled until complete user-confirmed GPIO mappings pass validation.
- NMO432 is 3.3 V I2S with SCK/BCLK, WS/LRCLK, SD/DIN, and explicit left/right channel selection.
- Every destructive erase requires an explicit checkbox plus confirmation naming the COM port.
- Each completed task receives a focused commit and push; no secrets may be committed.

## File Structure

- Create `host_pc/stroke_host/demo/cloud_client.py`: authenticated VPS session and normalized monitor states.
- Create `host_pc/stroke_host/deployment/schema.py`: deployment YAML models, environment expansion, validation, and redaction.
- Create `host_pc/stroke_host/deployment/idf_runner.py`: ESP-IDF discovery, safe command construction, staged subprocess execution, cancellation.
- Create `host_pc/stroke_host/deployment/serial_monitor.py`: COM discovery and stoppable text monitoring.
- Create `host_pc/stroke_host/demo/window.py`: dual-page PyQt5 application and worker wiring.
- Modify `host_pc/stroke_host/demo_entry.py`: launch only the new demo application.
- Create `host_pc/config/device-deployment.example.yaml`: credential-free NMO432/GC2145 template.
- Modify `.gitignore`: exclude local deployment YAML, generated sdkconfig overlay, logs, and environment files.
- Modify `host_pc/pyproject.toml`: runtime/test dependencies required by the focused app.
- Modify `scripts/build_release.ps1`: collect only required modules/assets and validate release exclusions.
- Modify `README.md`, `host_pc/README.md`, `docs/developer-handoff.md`: launch, maintenance, and safety instructions.
- Create tests under `host_pc/tests/` matching each service and UI boundary.

---

### Task 1: Real VPS Monitor Client

**Files:**
- Create: `host_pc/stroke_host/demo/__init__.py`
- Create: `host_pc/stroke_host/demo/cloud_client.py`
- Test: `host_pc/tests/test_desktop_cloud_client.py`

**Interfaces:**
- Produces: `CloudClient(base_url: str, timeout_seconds: float = 5.0)`.
- Produces: `login(username: str, password: str) -> None`, `connect(device_id: str) -> None`, `fetch_device() -> DeviceSnapshot`, `logout() -> None`.
- Produces: `CloudUnavailable`, `AuthenticationRequired`, `DeviceOffline`, and immutable `DeviceSnapshot`/`AdviceSnapshot` value objects.

- [ ] **Step 1: Write failing contract tests**

  Test real `httpx.MockTransport` request/response handling for successful login/connect/fetch, `401`, timeout, offline `404/409`, `null` modalities, and advice timestamps. Assert the returned object never synthesizes missing scores.

- [ ] **Step 2: Verify RED**

  Run: `host_pc\.venv\Scripts\python.exe -m pytest -q host_pc\tests\test_desktop_cloud_client.py`
  Expected: collection fails because `stroke_host.demo.cloud_client` does not exist.

- [ ] **Step 3: Implement the minimal cloud client**

  Use one `httpx.Client` with cookie persistence. Normalize only the existing `/demo/api/login`, `/connect`, `/device`, and `/logout` payloads. Map transport failures and HTTP states to the four explicit application states without retaining passwords.

- [ ] **Step 4: Verify GREEN and regression**

  Run: `host_pc\.venv\Scripts\python.exe -m pytest -q host_pc\tests\test_desktop_cloud_client.py host_pc\tests\test_demo_api.py`
  Expected: all selected tests pass.

- [ ] **Step 5: Commit and push**

  Commit: `feat(demo): add real VPS monitor client`

### Task 2: Deployment YAML Contract

**Files:**
- Create: `host_pc/stroke_host/deployment/__init__.py`
- Create: `host_pc/stroke_host/deployment/schema.py`
- Create: `host_pc/config/device-deployment.example.yaml`
- Modify: `.gitignore`
- Test: `host_pc/tests/test_deployment_schema.py`

**Interfaces:**
- Produces: `load_deployment(path: Path, environ: Mapping[str, str]) -> DeploymentConfig`.
- Produces: `validate_deployment(data: object, environ: Mapping[str, str]) -> DeploymentConfig`.
- Produces: `redact_text(text: str, config: DeploymentConfig) -> str`.
- `DeploymentConfig` exposes a whitelist mapping to current `CONFIG_STROKEGUARD_*` keys; it never exposes a shell command string.

- [ ] **Step 1: Write failing YAML validation tests**

  Cover the approved schema, environment substitution, unknown keys, malformed IDs/URIs, missing secrets, unsupported hardware models, incomplete GC2145/NMO432 pins, duplicate GPIOs, invalid channel, and redaction of every secret.

- [ ] **Step 2: Verify RED**

  Run: `host_pc\.venv\Scripts\python.exe -m pytest -q host_pc\tests\test_deployment_schema.py`
  Expected: collection fails because the deployment package is absent.

- [ ] **Step 3: Implement strict parsing and template**

  Parse with `yaml.safe_load`; reject unknown fields. Resolve only `${UPPER_CASE_NAME}` placeholders from the supplied environment. Keep camera/microphone disabled with empty pins in the tracked example. Map NMO432 pins to the existing audio Kconfig keys while presenting the corrected module name in YAML/UI.

- [ ] **Step 4: Verify GREEN**

  Run: `host_pc\.venv\Scripts\python.exe -m pytest -q host_pc\tests\test_deployment_schema.py`
  Expected: all tests pass and the fixture output contains no literal secret.

- [ ] **Step 5: Commit and push**

  Commit: `feat(device): add secure deployment YAML contract`

### Task 3: Controlled ESP-IDF and Serial Services

**Files:**
- Create: `host_pc/stroke_host/deployment/idf_runner.py`
- Create: `host_pc/stroke_host/deployment/serial_monitor.py`
- Test: `host_pc/tests/test_idf_runner.py`
- Test: `host_pc/tests/test_serial_monitor.py`

**Interfaces:**
- Produces: `IdfInstallation.discover(preferred: Path | None) -> IdfInstallation` with exact v5.5.3 validation.
- Produces: `IdfRunner.prepare(config)`, `build()`, `erase(port, confirmed)`, `flash(port)`, `cancel()` and stage events.
- Produces: `list_serial_ports() -> list[SerialPortInfo]` and `SerialMonitor.start(port, baud, on_line)`, `stop()`.

- [ ] **Step 1: Write failing safe-runner tests**

  Inject a fake process launcher and assert argument arrays, stage transitions, cancellation, non-zero exit behavior, no free-form shell invocation, no secrets in events, confirmation enforcement, and generated config cleanup. Test serial enumeration and port release with an injected serial factory.

- [ ] **Step 2: Verify RED**

  Run: `host_pc\.venv\Scripts\python.exe -m pytest -q host_pc\tests\test_idf_runner.py host_pc\tests\test_serial_monitor.py`
  Expected: collection fails because runner modules do not exist.

- [ ] **Step 3: Implement staged services**

  Launch the IDF export environment through a fixed PowerShell script path and pass commands as argument arrays. Generate a local ignored sdkconfig defaults overlay from the YAML whitelist. Stream decoded output through `redact_text`; terminate child processes on cancellation and always close serial handles.

- [ ] **Step 4: Verify GREEN**

  Run: `host_pc\.venv\Scripts\python.exe -m pytest -q host_pc\tests\test_idf_runner.py host_pc\tests\test_serial_monitor.py`
  Expected: all tests pass.

- [ ] **Step 5: Commit and push**

  Commit: `feat(device): add controlled IDF flashing services`

### Task 4: Focused Dual-Mode PyQt Application

**Files:**
- Create: `host_pc/stroke_host/demo/window.py`
- Modify: `host_pc/stroke_host/demo_entry.py`
- Modify: `host_pc/stroke_host/ui/theme.py`
- Test: `host_pc/tests/test_focused_demo_window.py`
- Test: `host_pc/tests/test_release_packaging.py`

**Interfaces:**
- Consumes: `CloudClient`, `DeploymentConfig`, `IdfRunner`, and `SerialMonitor` from Tasks 1-3.
- Produces: `DemoWindow` and `main()`; `demo_entry.py` imports only `stroke_host.demo.window.main`.

- [ ] **Step 1: Write failing UI structure tests**

  Use `pytest-qt` to assert login-first behavior, automatic `sg-0001` connection, six metric values, explicit cloud/auth/device/missing-data states, stale timestamp, advice panel, maintenance navigation, destructive confirmation, disabled conflicting actions, and cleanup on close. Assert no simulation/source/FPS/record/perception controls exist.

- [ ] **Step 2: Verify RED**

  Run: `host_pc\.venv\Scripts\python.exe -m pytest -q host_pc\tests\test_focused_demo_window.py host_pc\tests\test_release_packaging.py`
  Expected: tests fail because the focused window is absent and entry point still imports the legacy window.

- [ ] **Step 3: Build the presentation dashboard**

  Implement a restrained clinical operations aesthetic: off-white content surface, charcoal text, green/amber/red only for state, compact status dots, large readable metric numerals, and one advice region. Poll every five seconds on a worker thread; never block the Qt event loop. Keep the last snapshot visible but visibly stale after failure.

- [ ] **Step 4: Build the maintenance page**

  Add structured YAML fields, masked secret status, COM/IDF selectors, five-stage progress, explicit erase acknowledgement, start/cancel controls, and a readable redacted log. Hardware toggles reveal GPIO fields only when enabled; incomplete pin sets block execution with field-level errors.

- [ ] **Step 5: Verify GREEN and visual behavior**

  Run: `host_pc\.venv\Scripts\python.exe -m pytest -q host_pc\tests\test_focused_demo_window.py host_pc\tests\test_release_packaging.py host_pc\tests\test_ui_theme.py`
  Expected: all selected tests pass.

- [ ] **Step 6: Commit and push**

  Commit: `feat(demo): replace desktop tool with focused presentation app`

### Task 5: Documentation and Release Packaging

**Files:**
- Modify: `host_pc/pyproject.toml`
- Modify: `scripts/build_release.ps1`
- Modify: `README.md`
- Modify: `host_pc/README.md`
- Modify: `docs/developer-handoff.md`
- Modify: `host_pc/tests/test_demo_deploy_contract.py`
- Modify: `host_pc/tests/test_release_packaging.py`

**Interfaces:**
- Produces: rebuilt `dist/StrokeGuard-Demo.exe` and `dist/StrokeGuard-Developer-Handoff.zip`.

- [ ] **Step 1: Write failing release contract tests**

  Require the new entry point/modules/example YAML in handoff, forbid local deployment files/generated sdkconfig/secrets/logs, and assert the release script excludes legacy heavyweight perception dependencies from the demo entry graph where PyInstaller permits.

- [ ] **Step 2: Verify RED**

  Run: `host_pc\.venv\Scripts\python.exe -m pytest -q host_pc\tests\test_demo_deploy_contract.py host_pc\tests\test_release_packaging.py`
  Expected: at least one new release assertion fails.

- [ ] **Step 3: Update dependencies, packaging, and operator docs**

  Document prerequisites, login, default real-device behavior, YAML environment variables, IDF discovery, COM workflow, erase warning, NMO432 wiring labels, and the limitation that GC2145/NMO432 drivers remain pending until GPIOs and drivers are completed.

- [ ] **Step 4: Run full verification**

  Run: `host_pc\.venv\Scripts\python.exe -m pytest -q`
  Expected: all tests pass with zero failures.

- [ ] **Step 5: Build artifacts**

  Run: `powershell -ExecutionPolicy Bypass -File scripts\build_release.ps1`
  Expected: exactly `StrokeGuard-Demo.exe` and `StrokeGuard-Developer-Handoff.zip` in `dist`, each with SHA-256 output.

- [ ] **Step 6: Smoke-test EXE**

  Launch the EXE, verify the login window appears, confirm no simulation controls, close it, and verify no orphan process remains. Open the ZIP and repeat the forbidden-entry scan.

- [ ] **Step 7: Commit and push**

  Commit: `feat(release): deliver focused StrokeGuard demo app`

### Task 6: Real Hardware Acceptance

**Files:**
- Create: `docs/demo-acceptance-checklist.md`
- Update tests only if a real-device defect is reproduced.

**Interfaces:**
- Consumes: installed EXE, VPS, `sg-0001`, COM port, N16R8 board, approved local deployment YAML.
- Produces: evidence-backed acceptance record without invented accuracy claims.

- [ ] **Step 1: Run cloud acceptance**

  Log in, verify `sg-0001` online, confirm changing real CSI, `null` F/S/T/E shown as “未接入”, S3 level preserved, and completed Doubao advice shown with source/time.

- [ ] **Step 2: Run failure acceptance**

  Disconnect network and then stop S3 uplink separately. Verify the UI distinguishes cloud unreachable from device offline and never creates replacement scores.

- [ ] **Step 3: Run maintenance dry run**

  Load the credential-resolved local YAML, detect the actual COM port and IDF v5.5.3, validate N16R8, and build without enabling unconfirmed GC2145/NMO432 pins.

- [ ] **Step 4: Run destructive flow only with user confirmation**

  After explicit approval, erase, flash, monitor boot, and verify the board resumes independent MQTT uplink. If approval is not given, record erase/flash as not executed rather than claiming success.

- [ ] **Step 5: Record artifact hashes and commit**

  Commit: `test(demo): record focused app acceptance`

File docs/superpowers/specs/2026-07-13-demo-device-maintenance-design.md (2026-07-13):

# StrokeGuard 初赛演示与设备维护程序设计

日期：2026-07-13  
状态：已确认，待实施

## 1. 目标

将 `StrokeGuard-Demo.exe` 从完整 PC 开发工具精简为面向初赛的双模式程序：

1. 默认“实时演示”模式只展示 VPS 上真实设备 `sg-0001` 的监控数据和豆包建议。
2. 独立“设备维护”模式负责部署 YAML、COM 连接、ESP-IDF 编译、擦除、烧录及串口日志监视。
3. 不生成或回退到模拟数据；网络、会话或设备异常必须明确显示真实状态。
4. 原始音视频始终只在设备本地处理，演示程序和云端只读取结构化数值与建议文本。

## 2. 运行边界

- 目标硬件为 ESP32-S3-WROOM-1 N16R8。
- PC 不是镜端运行依赖，只承担演示监控和开发维护。
- VPS/FastAPI/EMQX 仍是远程监控数据来源；S3 风险等级为权威结果。
- EXE 不内置 ESP-IDF 工具链。维护模式检测并调用本机 ESP-IDF v5.5.3，默认路径为 `E:\esp\v5.5.3\esp-idf`，并允许用户选择其他有效路径。
- 首期默认设备为 `sg-0001`，实现保留更换设备 ID 的配置能力，不增加多用户和设备所有权系统。

## 3. 信息架构

### 3.1 实时演示

实时演示是启动后的默认页面，只保留评委需要观察的内容：

- 产品名称、当前设备 ID、云端状态和设备在线状态。
- F、S、T、E、CSI、最终评分。
- S3 风险等级、否决项和结构化原因。
- 最新豆包建议、建议来源和完成时间。
- 隐私说明和医疗免责声明。
- 进入设备维护页的次要入口。

删除模拟源、FPS、原始帧、算法后端、数据记录、开发日志和重复的成功提示。未接入模态显示“未接入”，不得显示默认分数。断网时保留最后一次数据但显著标注“非实时”，并显示最后更新时间；不得继续动画或伪装为在线。

状态必须区分：

- `云端不可达`：HTTP 请求无法到达 VPS。
- `登录失效`：服务器返回未授权，要求重新登录。
- `设备离线`：云端可达，但最近 30 秒没有目标设备上行。
- `数据未接入`：设备在线，但具体模态值为 `null`。

### 3.2 登录

程序启动后由用户输入 VPS 演示账号和密码。凭据只用于建立当前进程的会话，不写入 EXE、YAML、日志或本地长期存储。登录成功后自动绑定默认设备 `sg-0001`。

### 3.3 设备维护

设备维护页与演示页视觉和职责隔离，包含：

- 自动扫描可用 COM 口、刷新和手动选择。
- 芯片探测，拒绝将 N16R8 配置无提示地用于不匹配目标。
- 打开、编辑和校验部署 YAML。
- ESP-IDF 路径和版本检查。
- 分阶段操作：配置校验、编译、擦除、烧录、串口监视。
- 可停止的串口监视和脱敏日志。

擦除是破坏性操作，只有用户明确勾选“允许擦除目标设备”并再次确认目标 COM 口后才执行。编译、擦除或烧录期间禁用冲突操作。退出程序时必须终止子进程并释放串口。

## 4. 部署 YAML

部署 YAML 不包含用户医学档案，结构如下：

```yaml
schema_version: 1

device:
  id: sg-0001
  management_token: ${STROKEGUARD_MANAGER_TOKEN}

wifi:
  ssid: ${STROKEGUARD_WIFI_SSID}
  password: ${STROKEGUARD_WIFI_PASSWORD}

mqtt:
  uri: mqtt://example:1883
  username: ${STROKEGUARD_MQTT_USERNAME}
  password: ${STROKEGUARD_MQTT_PASSWORD}

hardware:
  camera:
    model: GC2145
    enabled: false
    pins: {}
  microphone:
    model: NMO432
    enabled: false
    sample_rate: 16000
    channel: left
    pins: {}
```

真实密钥由进程环境变量或被 Git 忽略的本地 `.env` 提供。界面默认遮挡敏感字段，日志统一替换为 `***`。模板、测试夹具和发布包不得包含真实凭据。

校验规则：

- `schema_version` 必须为 `1`。
- `device.id` 必须符合现有 MQTT 设备 ID 约束且不能为空。
- Wi-Fi SSID、MQTT URI 和必需凭据必须解析成功后才能编译。
- 摄像头仅支持声明 `GC2145`，麦克风仅支持声明 `NMO432`。
- NMO432 固定使用 3.3V 供电和 I2S 接口；YAML 必须声明 `SCK/BCLK`、`WS/LRCLK`、`SD/DIN` GPIO 以及与 `L/R` 接法一致的左右声道。`VDD` 接 3.3V，`GND` 接公共地，不允许接 5V。
- 启用 GC2145 或 NMO432 时必须提供固件 Kconfig 要求的全部 GPIO；缺失、重复、越界或保留引脚均阻止编译。
- 本阶段不猜测任何 GPIO，也不自动启用未确认硬件。

## 5. ESP-IDF 集成

维护程序通过受控子进程调用 ESP-IDF，不拼接未经校验的自由文本命令。预期阶段为：

1. 检测 IDF v5.5.3、Python 环境、工程目录和目标 COM 口。
2. 将已校验 YAML 转换为本次构建使用的本地配置；配置文件必须被 Git 忽略。
3. 执行 `idf.py set-target esp32s3` 和 `idf.py build`。
4. 可选执行 `idf.py -p <PORT> erase-flash`。
5. 执行 `idf.py -p <PORT> flash`。
6. 执行 `idf.py -p <PORT> monitor` 或等价串口监视，并展示经过脱敏的输出。

YAML 到 Kconfig 的映射必须使用明确字段白名单。禁止把密码放入命令行参数或 UI 错误弹窗；生成配置的落盘位置和清理策略需由实现测试覆盖。

## 6. 错误处理

- 每个阶段返回独立状态：待执行、运行中、成功、失败、已取消。
- 失败时展示阶段、简明原因和可操作建议，完整脱敏输出留在维护日志中。
- COM 被占用时不自动杀死其他程序，提示用户关闭占用者。
- 烧录失败后不宣称设备可用；只有启动日志和 VPS 上行均通过才显示“验收通过”。
- VPS 不可用不影响设备维护；ESP-IDF 不可用不影响远程演示。

## 7. 视觉原则

- 实时演示采用安静、医疗监护风格，评分数字清晰，状态灯尺寸克制。
- 主要页面不使用开发术语和大段使用说明。
- 维护页使用步骤状态和结构化表单，不暴露无意义的底层反馈。
- 所有按钮文案表示明确命令；危险操作采用警示色和二次确认。
- 适配 1366x768 及更高 Windows 桌面分辨率，文本不得重叠或截断。

## 8. 测试与验收

### 自动测试

- VPS 客户端：登录、会话失效、超时、设备离线和 `null` 模态。
- YAML：正常配置、缺字段、未知字段、环境变量缺失、GPIO 冲突和凭据脱敏。
- IDF 任务：命令白名单、阶段状态、取消、非零退出码和串口释放。
- UI：无模拟入口、默认真实设备、离线状态、危险操作确认和退出清理。
- 发布：EXE 可启动，发布包不含 `.env`、本地 YAML、`sdkconfig`、日志或密钥。

### 人工验收

1. 启动 EXE，登录后自动连接 `sg-0001`。
2. S3 在线时显示真实 CSI、融合等级和豆包建议。
3. F/S/T/E 为 `null` 时显示“未接入”，不生成数字。
4. 断开 VPS 网络后明确显示“云端不可达”和最后更新时间。
5. 选择 COM 口，加载有效 YAML，完成编译和烧录。
6. 未确认擦除、引脚缺失或板型不匹配时操作被阻止。
7. 串口日志不出现 Wi-Fi、MQTT 或管理 Token 明文。
8. 烧录后设备独立运行，并恢复 VPS 实时上行。

## 9. 非目标

- 不实现模拟数据或答辩假数据。
- 不把 ESP-IDF、训练权重或原始音视频打包进 EXE。
- 不实现 OTA、设备远程控制、多用户账号、历史曲线或医学档案编辑。
- 不宣称尚未完成的 GC2145/NMO432 驱动或 F/S/T/E 真机能力已经可用。

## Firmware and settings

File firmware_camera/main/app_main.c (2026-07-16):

#include "camera_capture_adapter.h"
#include "camera_score_target.h"
#include "camera_usb_preview.h"

#include "driver/gpio.h"
#include "esp_log.h"
#include "freertos/FreeRTOS.h"
#include "freertos/task.h"

static const char *TAG = "sg_camera";

void app_main(void)
{
    sg_camera_source_observation_t observation;
    esp_err_t capture_err = sg_camera_capture_init();
    if (capture_err != ESP_OK) {
        ESP_LOGW(TAG, "camera acquisition unavailable; serving model_missing");
    }
    ESP_ERROR_CHECK(sg_camera_score_target_init());
    ESP_ERROR_CHECK(sg_camera_usb_preview_init());
    ESP_LOGI(TAG, "I2C idle levels SDA47=%d SCL48=%d",
             gpio_get_level(GPIO_NUM_47), gpio_get_level(GPIO_NUM_48));

    while (1) {
        sg_screening_control_t control;
        if (sg_camera_score_target_take_control(&control)) {
            ESP_ERROR_CHECK_WITHOUT_ABORT(sg_camera_capture_control(control));
        }
        (void)sg_camera_capture_observe(&observation);
        sg_camera_face_response_t bbox_response;
        sg_camera_face_metrics_response_t metrics_response;
        sg_camera_modal_response_t eye_response;
        sg_camera_modal_response_t tongue_response;
        sg_camera_stage_response_t stage_response;
        sg_camera_face_response_encode(&observation.face_bbox, &bbox_response);
        sg_camera_face_metrics_encode(
            &observation.face_metrics, &metrics_response);
        sg_camera_modal_encode(&observation.eye_metrics, &eye_response);
        sg_camera_modal_encode(&observation.tongue_metrics, &tongue_response);
        sg_camera_stage_encode(&observation.screening, &stage_response);
        esp_err_t err = sg_camera_score_target_serve(
            &bbox_response, &metrics_response, &eye_response,
            &tongue_response, &stage_response);
        if (err != ESP_OK && err != ESP_ERR_TIMEOUT) {
            ESP_LOGW(TAG, "I2C score serve failed: %s", esp_err_to_name(err));
        }
        vTaskDelay(pdMS_TO_TICKS(20));
    }
}

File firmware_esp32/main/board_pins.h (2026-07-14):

#pragma once

#include "sdkconfig.h"

#define SG_PIN_UNASSIGNED (-1)

#define SG_PIN_CAMERA_I2C_SDA CONFIG_STROKEGUARD_CAMERA_I2C_SDA
#define SG_PIN_CAMERA_I2C_SCL CONFIG_STROKEGUARD_CAMERA_I2C_SCL

#define SG_PIN_NMO432_BCLK CONFIG_STROKEGUARD_NMO432_BCLK
#define SG_PIN_NMO432_WS   CONFIG_STROKEGUARD_NMO432_WS
#define SG_PIN_NMO432_DIN  CONFIG_STROKEGUARD_NMO432_DIN

#define SG_PIN_ST7789_MOSI   CONFIG_STROKEGUARD_PIN_ST7789_MOSI
#define SG_PIN_ST7789_SCLK   CONFIG_STROKEGUARD_PIN_ST7789_SCLK
#define SG_PIN_ST7789_CS     CONFIG_STROKEGUARD_PIN_ST7789_CS
#define SG_PIN_ST7789_DC     CONFIG_STROKEGUARD_PIN_ST7789_DC
#define SG_PIN_ST7789_RST    CONFIG_STROKEGUARD_PIN_ST7789_RST
#define SG_PIN_ST7789_BL     CONFIG_STROKEGUARD_PIN_ST7789_BL

#define SG_PIN_MAX98357_BCLK CONFIG_STROKEGUARD_PIN_MAX98357_BCLK
#define SG_PIN_MAX98357_LRC  CONFIG_STROKEGUARD_PIN_MAX98357_LRC
#define SG_PIN_MAX98357_DIN  CONFIG_STROKEGUARD_PIN_MAX98357_DIN

#define SG_PIN_ALERT_RGB     CONFIG_STROKEGUARD_PIN_ALERT_RGB
#define SG_PIN_ALERT_BUZZER  CONFIG_STROKEGUARD_PIN_ALERT_BUZZER
#define SG_PIN_BUTTON_1      CONFIG_STROKEGUARD_PIN_BUTTON_1
#define SG_PIN_BUTTON_2      CONFIG_STROKEGUARD_PIN_BUTTON_2
#define SG_PIN_BUTTON_3      CONFIG_STROKEGUARD_PIN_BUTTON_3

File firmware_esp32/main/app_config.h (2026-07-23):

/**
 * @file app_config.h
 * @brief 卒中卫士 M1a 全局配置宏
 */
#pragma once

/* ==== 固件版本 ==== */
#define SG_FW_VERSION           "e1-0.5.2"

/* ==== USB-CDC 帧协议 v1 ==== */
#define SG_FRAME_MAGIC0         0xA5
#define SG_FRAME_MAGIC1         0x5A
#define SG_FRAME_VER            0x01

#define SG_FRAME_TYPE_HEARTBEAT 0x01
#define SG_FRAME_TYPE_DATA      0x02  /* M1b 起用 */
#define SG_FRAME_TYPE_SCORES    0x03  /* PC -> S3: 感知分数 */
#define SG_FRAME_TYPE_FUSION    0x04  /* S3 -> PC: 融合结果 */
#define SG_FRAME_TYPE_LOG       0xF0

#define SG_FRAME_HEADER_LEN     6     /* magic(2)+ver(1)+type(1)+len(2) */
#define SG_FRAME_CRC_LEN        2
#define SG_FRAME_MAX_PAYLOAD    1024  /* fusion 帧 reasons 会大一些 */

/* ==== CSI 参数 (v0.3: RuView 借鉴, 三特征融合) ==== */
#define SG_CSI_WINDOW_SEC       5
#define SG_CSI_WINDOW_MAX       55    /* 实测约 11 Hz，对应约 5 秒滑窗 */
#define SG_CSI_MIN_SAMPLES      16    /* 至少这么多样本才出分 (~1.5s @ 10Hz) */
#define SG_CSI_UPDATE_EVERY     5     /* 每 N 个新包更新一次分 */

/* 三特征融合权重 (总和 = 1.0), 来源: RuView README 信号处理章节 */
#define SG_CSI_W_AMP_CV         0.50f /* 幅度变异系数 (静止时 CV 小) */
#define SG_CSI_W_PHASE_VAR      0.00f /* 单子载波绝对相位实测不稳定，仅保留诊断 */
#define SG_CSI_W_MOTION_BAND    0.50f /* 运动带能量 (差分平方和, 反映动作剧烈度) */

/* 打分参数, 待实测标定 (M6);
 * v0.3.3: 相位改用圆方差 cvar in [0,1]. 静止 cvar~0.1, 动作 cvar~0.6 */
#define SG_CSI_K_AMP_CV         400.0f  /* 2026-07-23 COM3 初赛实测标定，待 M6 扩样本 */
#define SG_CSI_K_PHASE_VAR      100.0f  /* 静止 cvar=0.10 -> 90; 动作 0.5 -> 50 */
#define SG_CSI_K_MOTION         320.0f  /* 2026-07-23 COM3 初赛实测标定，待 M6 扩样本 */

/* ==== CSI Ping keep-alive (RuView 建议: 保证 CSI 包流量) ==== */
#define SG_CSI_PING_INTERVAL_MS 100   /* 10 Hz ICMP ping 网关, CSI 采样率主要靠这个 */
#define SG_CSI_PING_STACK       4096
#define SG_CSI_PING_PRIO        3
#define SG_CSI_PING_CORE        0

/* ==== 任务栈/优先级 ==== */
#define SG_TASK_HEARTBEAT_STACK 3072
#define SG_TASK_HEARTBEAT_PRIO  4
#define SG_TASK_HEARTBEAT_CORE  1

#define SG_TASK_FRAME_STACK     4096
#define SG_TASK_FRAME_PRIO      4
#define SG_TASK_FRAME_CORE      1
#define SG_FRAME_PERIOD_MS      1000  /* synthetic M1 frame, replace after sensors arrive */

#define SG_TASK_CSI_STACK       4096
#define SG_TASK_CSI_PRIO        5
#define SG_TASK_CSI_CORE        1

#define SG_TASK_CDC_TX_STACK    4096
#define SG_TASK_CDC_TX_PRIO     6
#define SG_TASK_CDC_TX_CORE     1

/* ==== 队列 ==== */
#define SG_CDC_TX_QUEUE_LEN     8
#define SG_CSI_RAW_QUEUE_LEN    32
#define SG_SCORES_RX_QUEUE_LEN  8

/* ==== 融合任务 ==== */
#define SG_TASK_FUSION_STACK    4096
#define SG_TASK_FUSION_PRIO     6
#define SG_TASK_FUSION_CORE     0
#define SG_TASK_FUSION_PERIOD_MS 1000
#define SG_SCORE_STALE_MS        5000
#define SG_MQTT_PUBLISH_PERIOD_MS 10000
#define SG_ADVICE_MAX_AGE_SEC       300

/* Medical screening thresholds are fixed and exposed read-only. */
#define SG_FACE_DANGER_MAX          30
#define SG_FACE_MOUTH_DEG_DANGER    20
#define SG_SPEECH_DANGER_MAX        35

#define SG_TASK_ADVICE_STACK    4096
#define SG_TASK_ADVICE_PRIO     5
#define SG_TASK_ADVICE_CORE     0

#define SG_CAMERA_POLL_PERIOD_MS 500
#define SG_TASK_CAMERA_STACK     4096
#define SG_TASK_CAMERA_PRIO      5
#define SG_TASK_CAMERA_CORE      0

#define SG_TASK_AUDIO_STACK      4096
#define SG_TASK_AUDIO_PRIO       5
#define SG_TASK_AUDIO_CORE       1

/* ==== CDC RX 任务 (JSON 帧解析) ==== */
#define SG_TASK_CDC_RX_STACK    4096
#define SG_TASK_CDC_RX_PRIO     5
#define SG_TASK_CDC_RX_CORE     0

/* ==== 启动延迟: USB 枚举稳定后再启 WiFi ==== */
#define SG_USB_TO_WIFI_DELAY_MS 2000

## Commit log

2026-07-11 chore: establish project source baseline
    [partitions.csv]
2026-07-11 feat(firmware): fuse locally produced edge scores
2026-07-11 feat(firmware): persist validated device configuration
2026-07-11 fix(cloud): reject nonnumeric device uplinks
2026-07-12 docs: design PC YAML device configuration
2026-07-12 docs: plan PC YAML device configuration
2026-07-13 feat(cloud): connect demo page to mqtt devices
2026-07-13 docs(firmware): add multi-device flashing guide
2026-07-13 docs(demo): specify focused device maintenance app
2026-07-13 feat(device): add secure deployment YAML contract
2026-07-13 feat(device): add controlled IDF flashing services
2026-07-14 docs(device): define camera coprocessor architecture
2026-07-14 docs(device): plan camera and NMO432 integration
2026-07-14 refactor(device): model camera coprocessor and NMO432
2026-07-14 feat(protocol): add camera score wire contract
2026-07-14 feat(device): poll camera score coprocessor
2026-07-14 feat(camera): add score coprocessor firmware
2026-07-14 chore(camera): exclude generated IDF artifacts
2026-07-14 docs(device): add camera and NMO432 bring-up
2026-07-14 feat(camera): integrate esp-who face coprocessor
    [partitions.csv]
2026-07-14 fix(camera): stabilize esp-who i2c coprocessor
    [camera_coprocessor.c, camera_score_target.c]
2026-07-14 docs(camera): design local USB preview
2026-07-14 docs(camera): plan USB preview implementation
2026-07-14 feat(camera): define USB preview protocol
2026-07-14 feat(camera): stream requested JPEG frames over USB
2026-07-14 feat(host): add local camera USB preview
2026-07-14 docs(camera): document USB preview workflow
2026-07-14 docs(camera): design YUV ESP-WHO pipeline
2026-07-14 fix(camera): stabilize GC2145 YUV capture
    [camera_capture_adapter.cpp]
2026-07-16 fix(camera): normalize RGB channels for face detection
    [camera_capture_adapter.cpp]
2026-07-16 fix(camera): complete bbox i2c bridge
    [app_main.c, camera_coprocessor.c]
2026-07-16 feat(face): add numeric F camera protocol
2026-07-16 feat(face): stabilize F over five frames
2026-07-16 feat(face): publish stabilized F from camera
    [app_main.c, camera_capture_adapter.cpp, camera_score_target.c]
2026-07-16 feat(face): feed camera F into edge fusion
2026-07-16 fix(face): map ESP-DL five landmarks correctly
    [camera_capture_adapter.cpp]
2026-07-16 feat(camera): add local eye movement scoring
2026-07-16 feat(camera): add auxiliary tongue deviation scoring
2026-07-16 feat(camera): run guided F E T screening
2026-07-16 docs(demo): document guided screening flow
2026-07-16 docs(camera): design reliable screening control
2026-07-16 docs(camera): plan screening reliability work
2026-07-16 fix(camera): latch screening controls reliably
    [camera_score_target.c]
2026-07-16 fix(edge): confirm camera screening controls
    [camera_coprocessor.c]
2026-07-16 feat(camera): stabilize guided face acquisition
    [camera_capture_adapter.cpp, camera_coprocessor.c]
2026-07-16 fix(camera): improve face detection stability
    [camera_capture_adapter.cpp]
2026-07-16 fix(camera): tune face screening for device frame rate
    [camera_capture_adapter.cpp, camera_usb_preview.c]
2026-07-16 fix(camera): advance face stage on valid window
2026-07-17 fix(camera): tolerate brief face detection gaps
2026-07-17 fix(camera): calibrate face baseline at QVGA
    [camera_capture_adapter.cpp]
2026-07-17 fix(edge): retain fresh face score for cloud monitor
    [camera_coprocessor.c]
2026-07-17 fix(camera): sample guided eye motion after prompts
2026-07-17 fix(camera): report discordant guided eye movement
    [camera_capture_adapter.cpp]
2026-07-17 fix(camera): score partial binocular eye response
    [camera_capture_adapter.cpp]
2026-07-17 fix(camera): detect pale tongue under front lighting
2026-07-17 fix(fusion): gate speech veto by model provenance
    [app_main.c]
2026-07-17 fix(speech): require explicit screening start
    [app_main.c]
2026-07-17 fix(test): restore device config after Unity run
2026-07-18 docs(mechanical): design desktop demonstrator enclosure
2026-07-18 docs(mechanical): plan desktop enclosure modeling
2026-07-18 test(mechanical): add enclosure geometry harness
2026-07-18 feat(mechanical): model split desktop enclosure body
    [parameters.scad, parts.scad, strokeguard_enclosure.scad]
2026-07-18 feat(mechanical): add adjustable electronics mounts
    [parameters.scad, parts.scad, strokeguard_enclosure.scad]
2026-07-18 build(mechanical): export verified enclosure models
    [base.stl, camera_bezel.stl, camera_carriage.stl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]
2026-07-18 feat(mechanical): publish TinkerCAD enclosure assembly
2026-07-18 docs(mechanical): add printable enclosure handoff
    [base.stl, camera_bezel.stl, camera_carriage.stl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]
2026-07-18 docs(mechanical): design split printed front panel
2026-07-18 feat(mechanical): model split printed front panel
    [parameters.scad, parts.scad, strokeguard_enclosure.scad]
2026-07-18 build(mechanical): export split front panel models
    [base.stl, camera_bezel.stl, camera_carriage.stl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]
2026-07-18 docs(mechanical): document split front panel printing
2026-07-18 docs(mechanical): design compact desktop enclosure
2026-07-18 docs(mechanical): plan compact enclosure implementation
2026-07-18 refactor(mechanical): define compact enclosure contract
    [parameters.scad, strokeguard_enclosure.scad]
2026-07-18 feat(mechanical): model compact desktop enclosure
    [parameters.scad, parts.scad]
2026-07-18 build(mechanical): export compact enclosure models
    [base.stl, camera_bezel.stl, camera_carriage.stl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]
2026-07-18 docs(mechanical): hand off compact enclosure
2026-07-18 fix(mechanical): eliminate compact shell overhangs
    [compact_shell.stl, parts.scad]
2026-07-18 fix(mechanical): remove desktop base overhang
    [desktop_base.stl, parts.scad]
2026-07-18 refactor(mechanical): define five-part enclosure contract
    [parameters.scad, strokeguard_enclosure.scad]
2026-07-18 feat(mechanical): add removable electronics tray
    [camera_clamp.stl, compact_shell.stl, controller_rail.stl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]
2026-07-19 docs(mechanical): plan first-print fit correction
2026-07-19 fix(mechanical): correct camera and rear-cover fit
    [compact_shell.stl, desktop_base.stl, electronics_tray.stl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]
2026-07-20 docs(mechanical): design tool-free PLA enclosure
2026-07-22 docs(camera): design single-wire score transport
2026-07-22 docs(camera): plan single-wire UART implementation
2026-07-22 feat(camera): add UART score protocol
2026-07-22 feat(camera): stream scores over UART
2026-07-22 feat(firmware): receive camera scores over UART
2026-07-22 docs(camera): document single-wire UART wiring
2026-07-22 test(camera): align standalone checks with UART
2026-07-22 fix(camera): allocate UART driver receive buffer
    [camera_score_uart.c]
2026-07-22 chore(camera): report UART receive diagnostics
2026-07-23 fix(screening): require explicit start and harden F/S
    [app_main.c, camera_capture_adapter.cpp, camera_coprocessor.c]
2026-07-23 fix(screening): reject lip color as tongue
    [camera_capture_adapter.cpp]
2026-07-23 fix(screening): stabilize scores and reject false tongue
    [app_main.c, camera_capture_adapter.cpp]
2026-07-23 fix(csi): calibrate balance motion scoring
    [app_config.h]
